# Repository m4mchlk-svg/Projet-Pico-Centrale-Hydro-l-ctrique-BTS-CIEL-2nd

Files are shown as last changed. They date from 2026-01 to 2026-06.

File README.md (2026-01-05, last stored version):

# Projet-Pico-Centrale-Hydro-l-ctrique-BTS-CIEL-2nd

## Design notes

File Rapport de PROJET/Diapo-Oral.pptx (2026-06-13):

## Présentation de Projet

Association Viseta

Descamps Anaël

## Sommaire

1. Partie personnelle
2. Collaboration
3. Diagrammes
4. Mesure et calcul de la consommation
5. Site et codes
6. Schéma et routage
7. Assemblage
8. Problèmes rencontrés
9. Conclusions

## 1) Partie personnelle

- Bilan de consommation : tableau comparatif consommation théorique vs mesurée (modes actif, repos, veille profonde)
- Mise en place du module MPPT et du panneau photovoltaïque et validation de l’autonomie
- Saisie de schéma et routage de la partie concernée du projet
- Programme de test
- Réalisation de l’IHM via une page Web fournie par le contrôleur principal (état du système ECVD et choix de la consigne du niveau d’eau)
- Intégration des différentes fonctions dans le programme final

## 2) Collaboration

Utilisation d’un GitHub pour le partage et l’avancement du projet

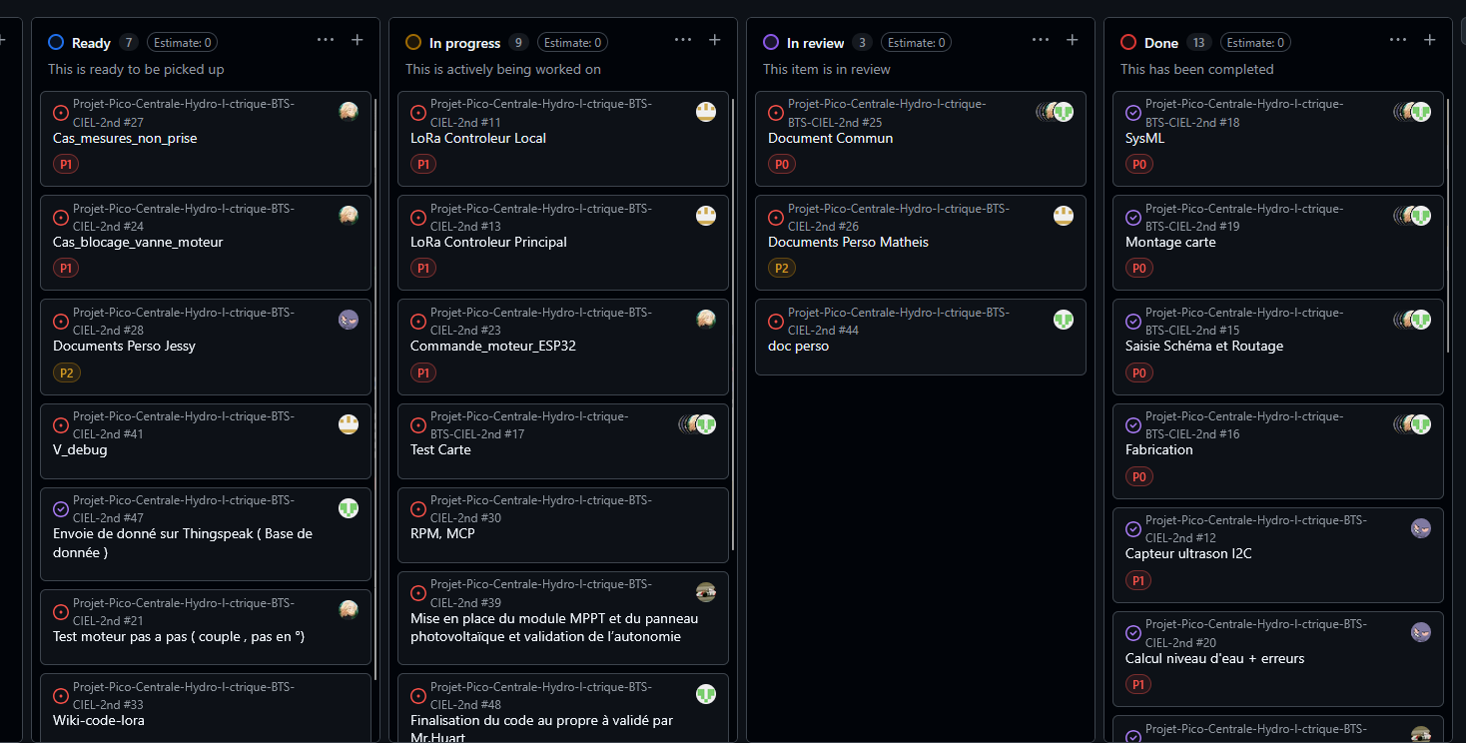
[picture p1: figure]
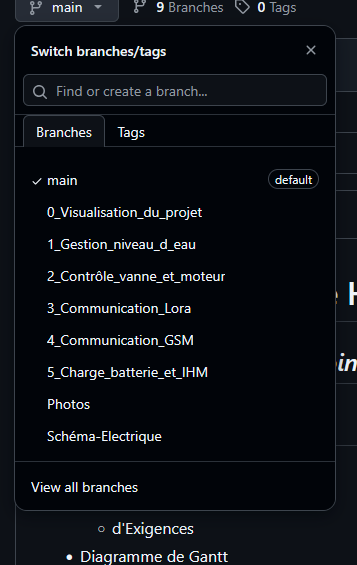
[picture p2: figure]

## 3) Diagrammes

Diagramme des cas d’utilisations

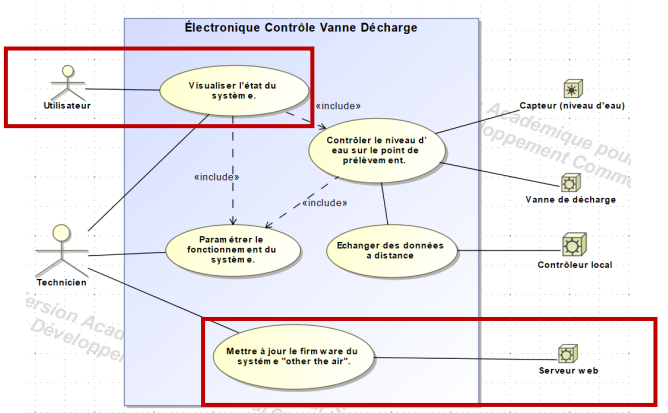
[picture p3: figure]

## 3) Diagrammes

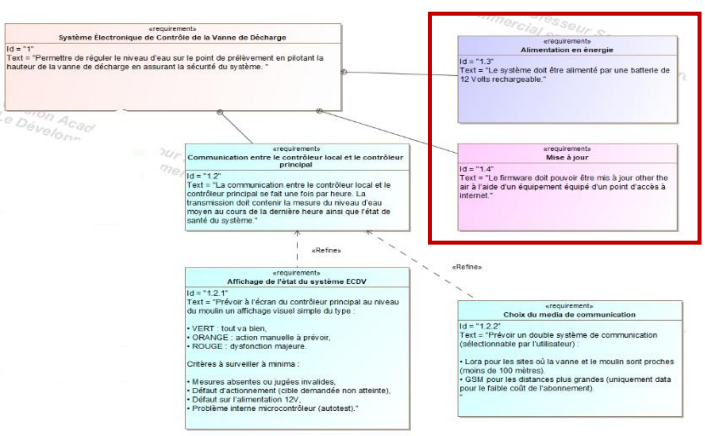
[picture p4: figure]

Diagramme des exigences

## 4) Mesure et calcul de la consommation

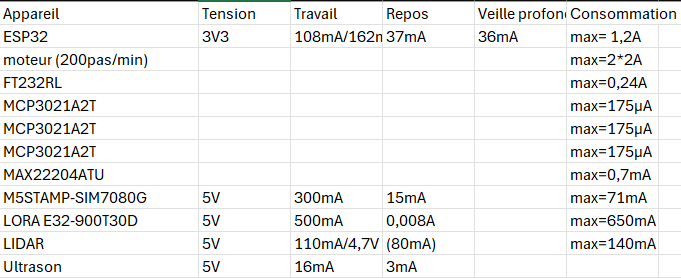
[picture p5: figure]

- Mesure de la consommation de chaque composant principal
- Consommation maximale, au repos et valeurs fabricant (datasheet)
- Composant le plus énergivore : moteur pas-à-pas (ancien moteur)
- Évolution du courant du moteur pas-à-pas en fonction de la vitesse
- Consommation se stabilise à partir d'un certain seuil
- Validation de la batterie 12V retenue pour l'autonomie du système

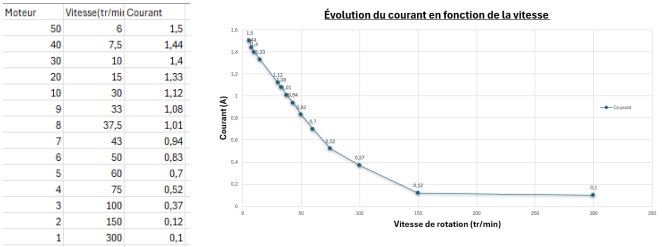
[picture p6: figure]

## 5) Site et codes

- Interface web embarquée (IHM)
- Page HTML hébergée directement sur l’ESP32
- L’ESP32 crée son propre réseau Wi-Fi, accessible directement depuis un téléphone
- Affichage en temps réel : hauteur d’eau, tension batterie, courant solaire
- Envoi des données vers ThingSpeak toutes les 15 secondes
- Accessible sans box ni internet : idéal pour un site isolé comme un moulin

## 5) Site et codes

- Algorigramme du site

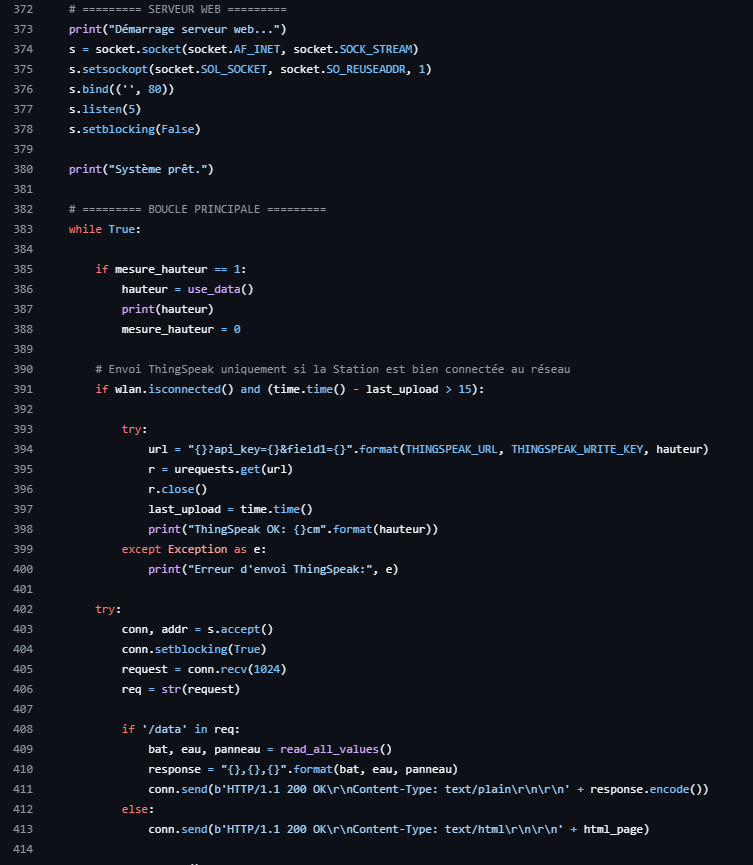
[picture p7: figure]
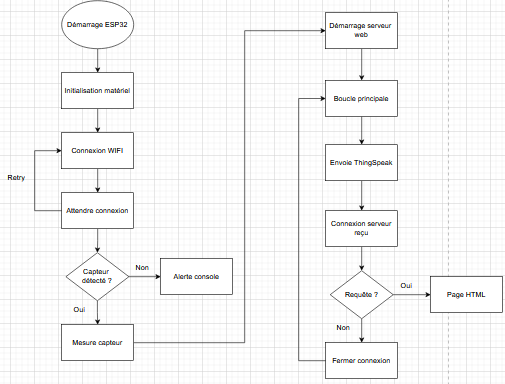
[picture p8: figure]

## 6) Schéma et routage

- Saisie du schéma (Proteus 8)
- Protection contre l’inversion de polarité : MOSFET
- MCP3021 convertisseur analogique numérique
- Régulateur de tension a découpage (U3) : pour convertir la tension 12V en 5V
- AZ1117 convertir la tension de 5V à 3V3

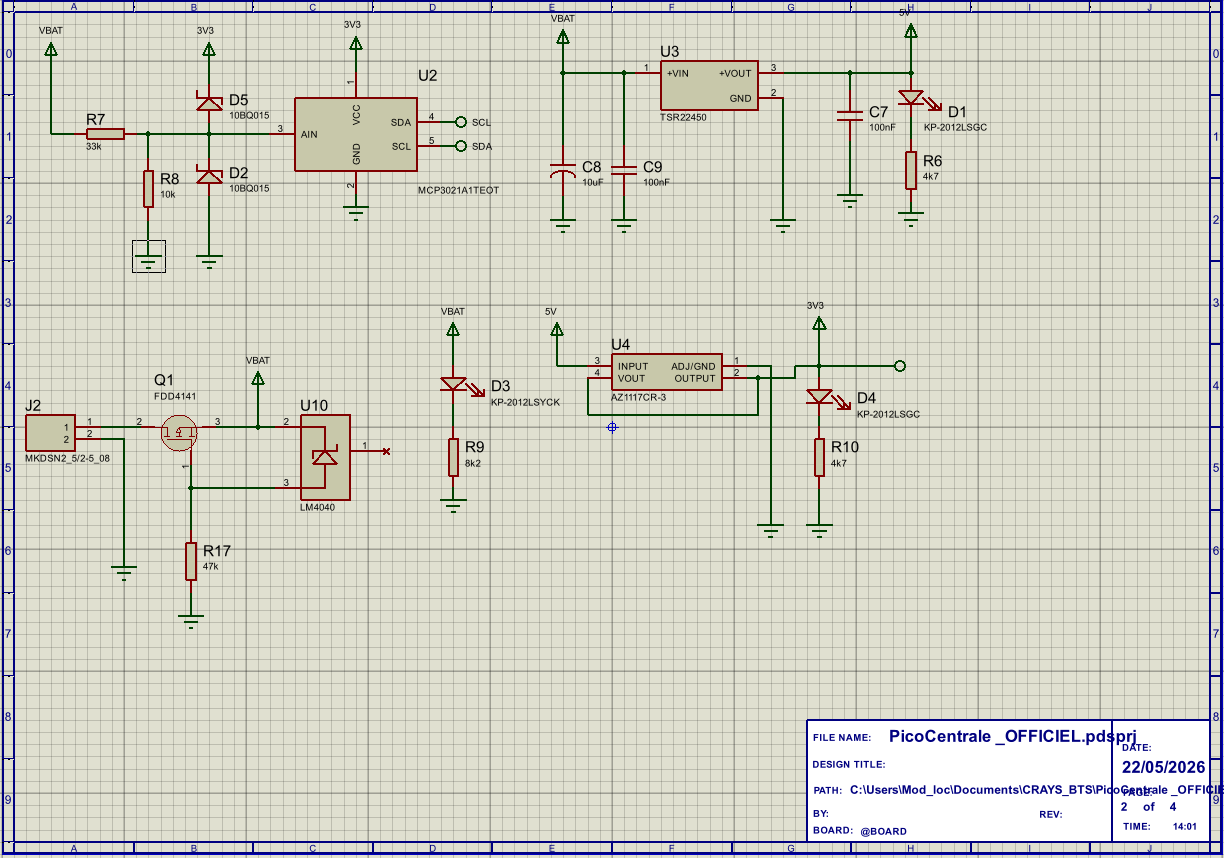
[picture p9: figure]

## 6) Schéma et routage

- Routage PCB
- Séparation des plans de masse numérique (GND) et puissance (VBAT)
- Condensateurs de découplage positionnés au plus près des circuits intégrés
- Pistes de puissance élargies pour la tenue en courant

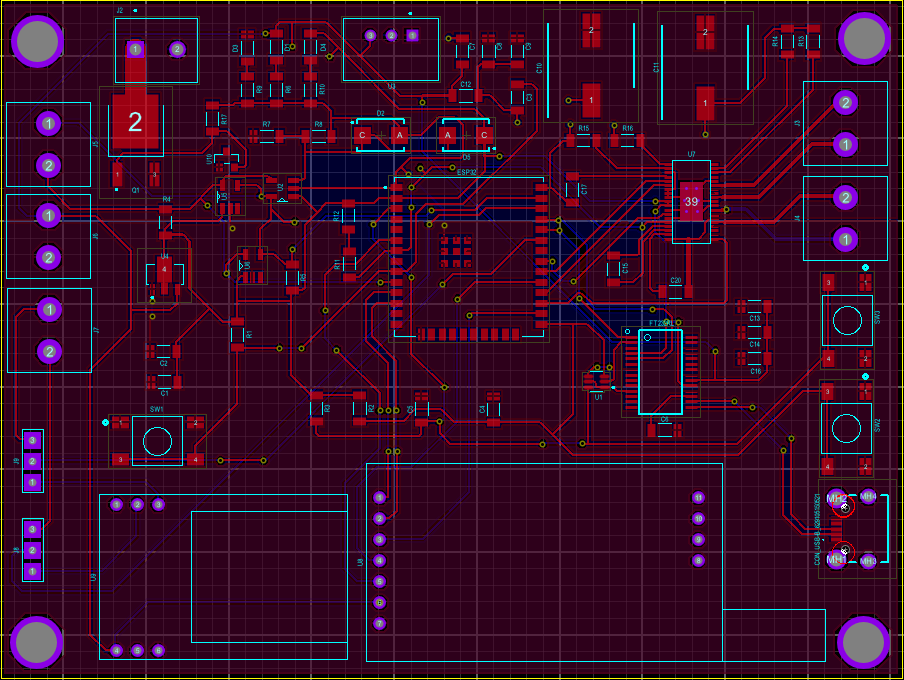
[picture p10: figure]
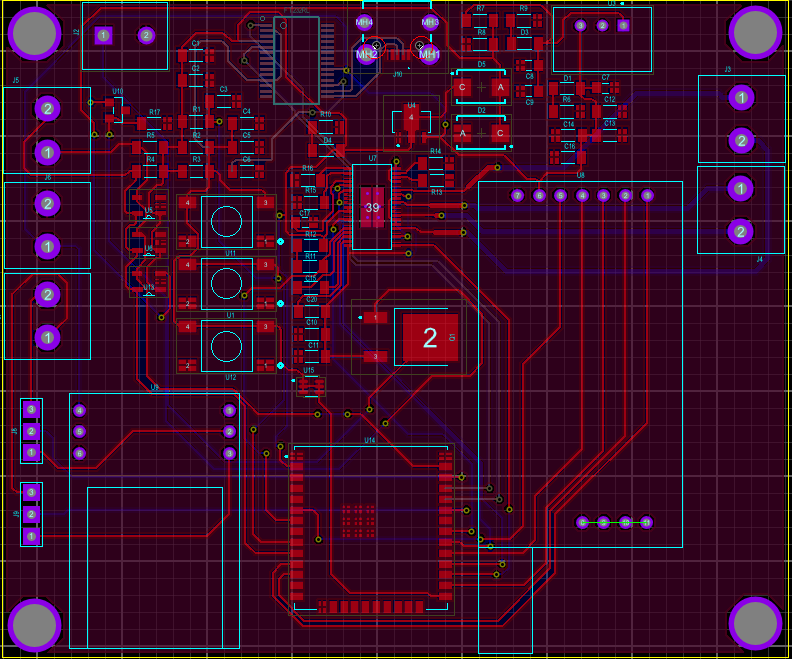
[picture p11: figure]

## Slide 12

6) Schéma et routage

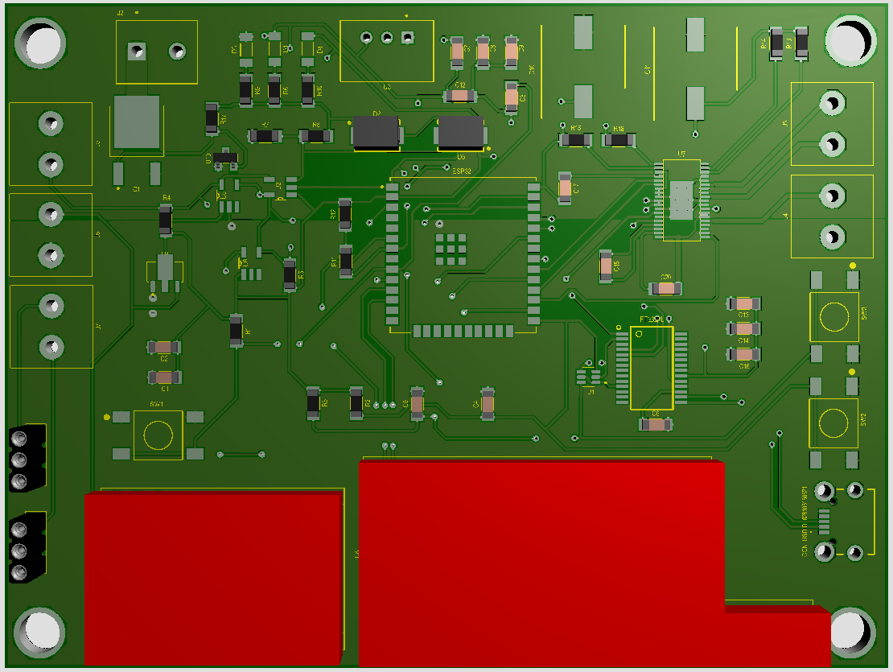
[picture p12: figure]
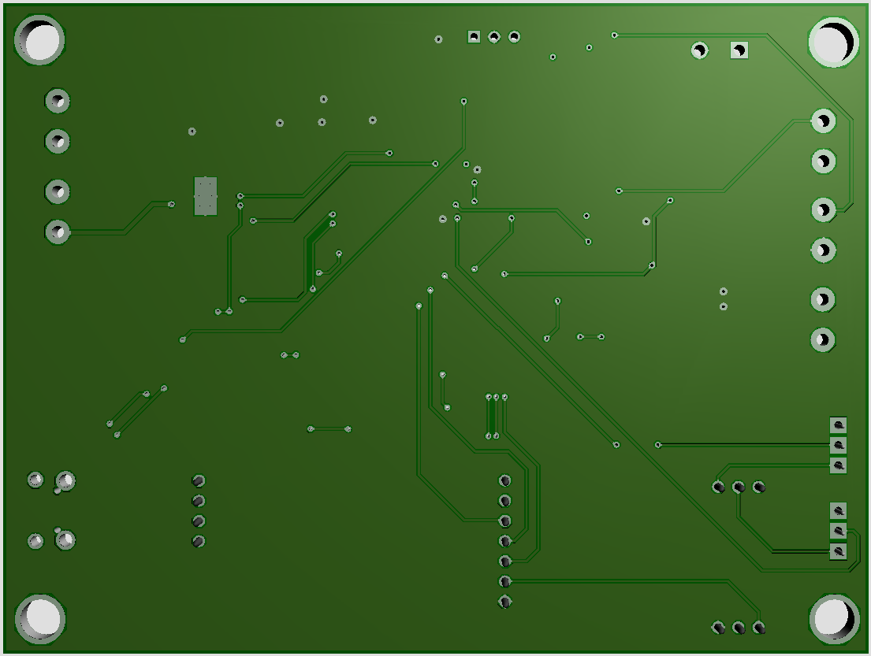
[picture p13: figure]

## 6) Assemblage de la carte

- Réalisé dans les locaux de la Licence CPSE
- Sérigraphie de la pâte à braser
- Pochoir métallique découpé précisément aux emplacements des pastilles PCB
- Étalement à la raclette en un seul passage (port de gants obligatoire)

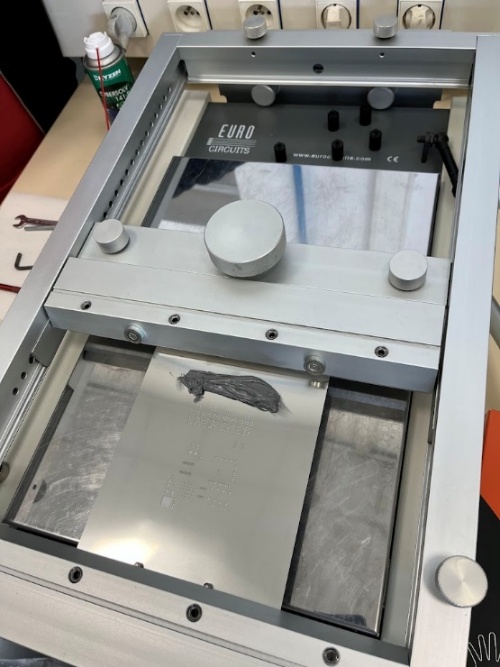
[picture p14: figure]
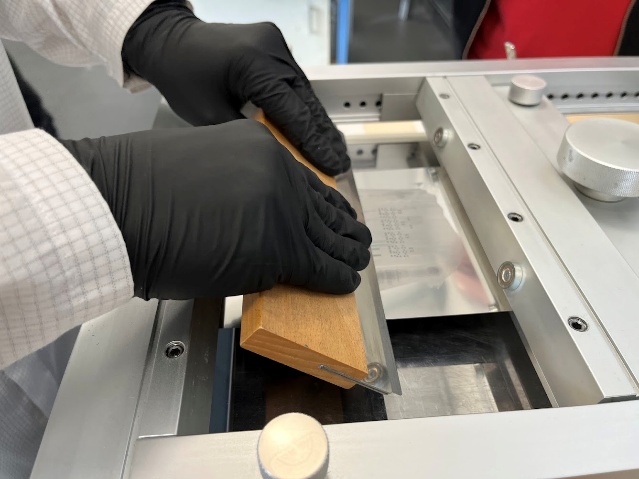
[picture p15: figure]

## 6) Assemblage de la carte

Pose des composants : placeuse à aspiration manuelle et placeuse automatique

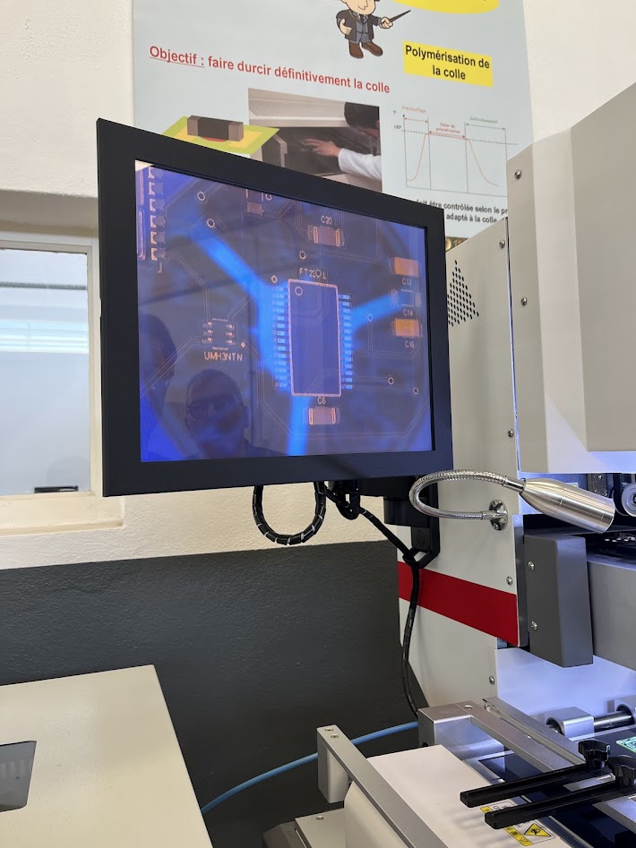
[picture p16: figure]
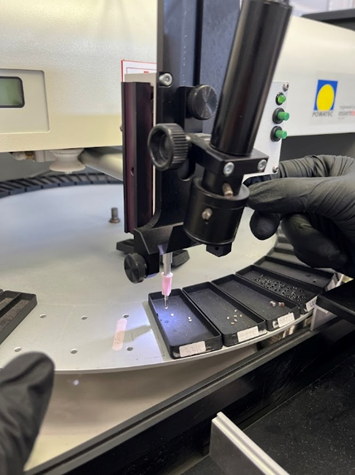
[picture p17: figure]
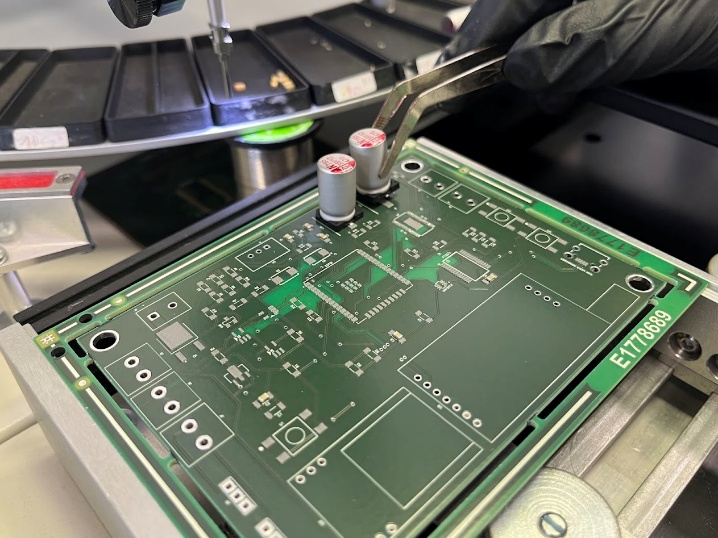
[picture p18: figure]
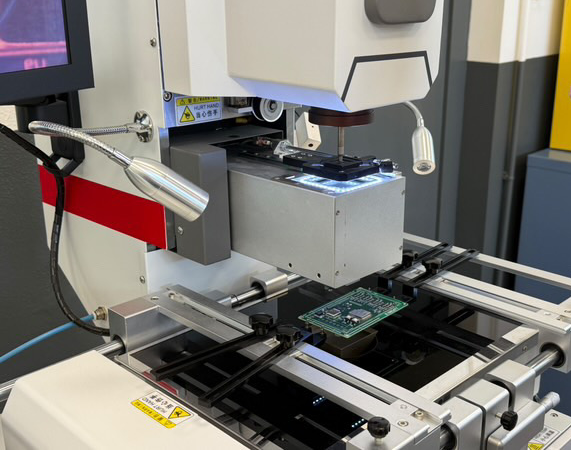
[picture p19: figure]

## 6) Assemblage de la carte

- Refusion au four avec un profil thermique une montée progressive(choc thermique), pic ~250°C puis refroidissement dégressif
- Inspection visuelle à la loupe : détection des ponts de soudure et soudures froides
- Tests fonctionnels bloc par bloc (Lidar, moteur, batterie, serveur web)

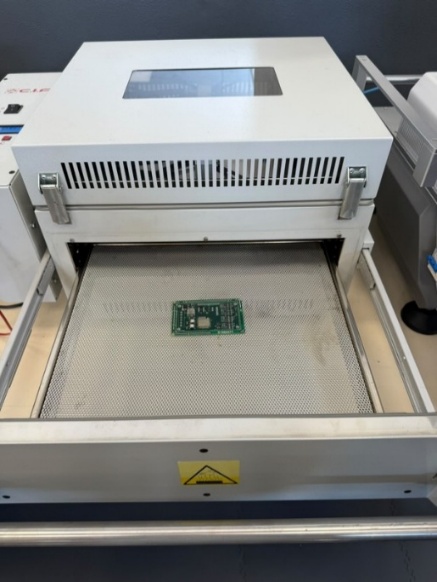
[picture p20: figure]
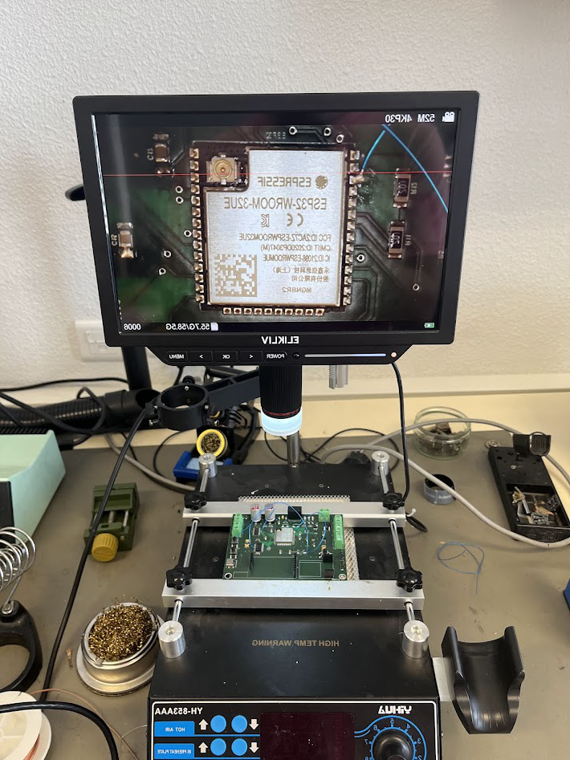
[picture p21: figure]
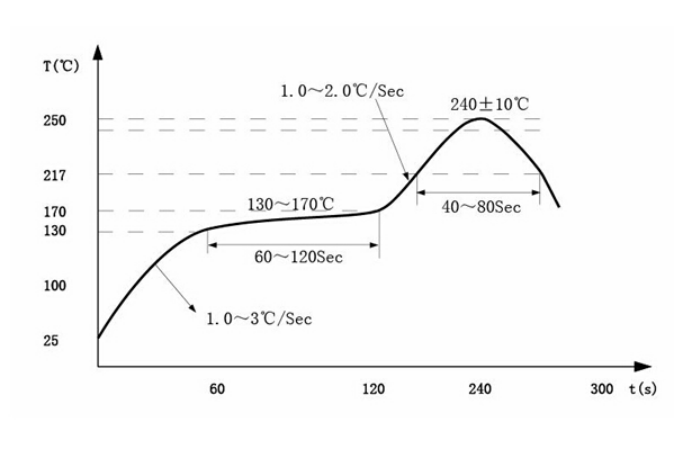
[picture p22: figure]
Type7 High Ag No Clean Solder Paste SAC305 Manufacturers and Suppliers China - Pricelist - BBIEN Technology

## 7) Problèmes rencontrés

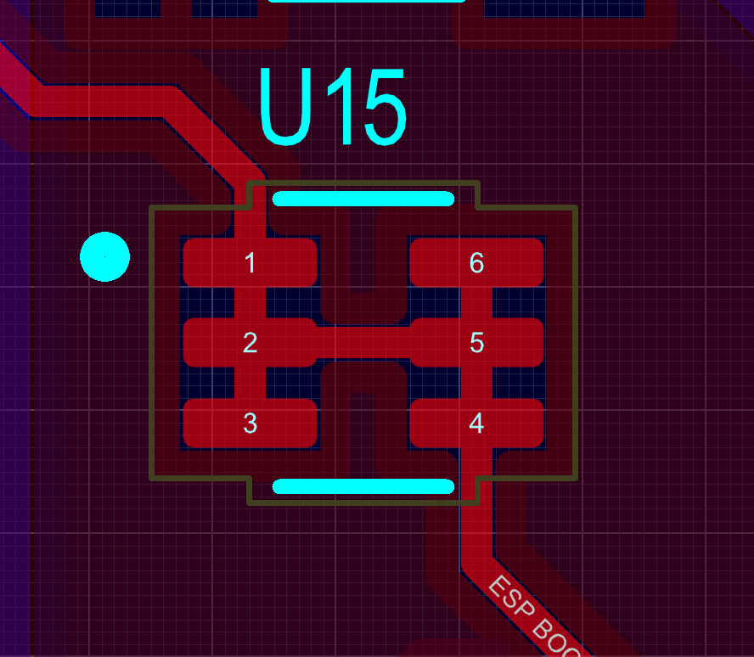
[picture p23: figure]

- Inversion des sorties moteur OUT1A / OUT1B au lieu de OUT1A/OUT2A
- Underscores oubliés dans ESP_RESET et ESP_BOOT
- Broche 18 du FT232RL non connectée au 3,3V
- Empreinte incorrecte sur l’UMH3NTN
- Hétérogénéité des empreintes de résistances

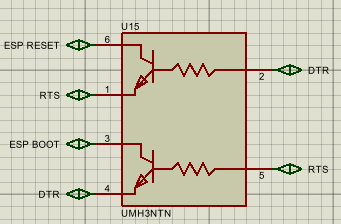
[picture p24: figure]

## 8) Conclusions

- Bilan
Bilan de consommation et dimensionnement de l’alimentation
Vérification et saisie du schéma d’alimentation sur Proteus
Routage PCB et assemblage CMS en conditions industrielles
Développement Micro-Python et une interface web embarquées sur ESP32
- Résultats
Système fonctionnel avec une page web accessible depuis un téléphone via Wi-Fi de l’ESP32,
Approche d’un système électronique autonome : énergie, hardware et software simultanément

## Merci

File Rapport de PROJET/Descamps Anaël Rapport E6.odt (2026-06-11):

BTS CIEL 921

2025-2026

Anaël DESCAMPS

Rapport de Projet


1. Introduction

Dans le cadre de ma formation en BTS CIEL option ER, il nous a été demandé de rédiger un rapport de projet individuel pour présenter le travail qu’on a réalisé tout au long de l’année.

Ce document fait suite au rapport commun intitulé “Rapport commun Pico-centrale hydroélectrique” et se concentre uniquement sur ma contribution personnelle dans ce projet. Pour rappel, l’association Viseta, basée dans les Hautes-Pyrénées, nous a confié la conception de l’électronique de contrôle de la vanne de décharge, qu’on appelle l’ECVD, pour équiper sa pico-centrale hydroélectrique. Une turbine est installée dans un ancien moulin abandonné, et notre système doit réguler automatiquement le niveau d’eau en amont de cette turbine. Pour cela, un capteur Lidar mesure la hauteur d’eau en continu, et en fonction de cette mesure, un moteur pas-à-pas ouvre ou ferme la vanne de décharge. Tout le système fonctionne de manière autonome grâce à une batterie 12V rechargée par un panneau solaire via un régulateur MPPT, ce qui évite d’avoir besoin d’une connexion au réseau électrique. C’est une solution adaptée pour des sites isolés comme des moulins en pleine campagne.

## 1.1. Remerciement

Avant de commencer, je voudrais remercier les personnes qui nous ont aidés et encadrés tout au long de ce projet. Sans leur suivi et leurs conseils, on n’aurait pas pu avancer aussi efficacement :

Toute l’équipe enseignante technique du lycée Antoine Bourdelle, pour les conseils qu’ils nous ont donnés et pour leur suivi régulier du projet, ce qui nous a vraiment permis d’avancer dans la bonne direction :

- M. ALARY

- M. HUART

- M. HAAS

## 1.2. Partie Personnelle

Dans le cadre du projet PICO centrale, j'ai travaillé principalement sur deux aspects : la supervision de la batterie et la conception de l'interface homme-machine (IHM) sous forme de page web embarquée. Ces deux parties sont étroitement liées, dans la mesure où l'IHM affiche en temps réel l'état de la batterie, des panneaux solaires connectés via le module MPPT, ainsi que les données transmises par le capteur de niveau d'eau. L'ensemble permet à l'opérateur de surveiller le système aisément depuis son téléphone.

### 1.2.1. Analyse des besoins énergétiques

J'ai commencé le projet par l'analyse des besoins énergétiques du système, une sous-estimation de la consommation risquerait de compromettre l'autonomie de la batterie la nuit ou par temps couvert. J'ai donc élaboré un tableau Excel recensant, d'une part, la consommation théorique maximale de chaque module, et d'autre part, les valeurs mesurées expérimentalement, en distinguant trois états de fonctionnement : mode actif, repos et veille profonde. Cette comparaison a permis d'évaluer l'écart entre les spécifications fabricant et la consommation réelle, d'identifier les éléments les plus énergivores le moteur pas-à-pas en premier lieu et de confirmer la conformité de la batterie retenue. J'ai également tracé la courbe d'évolution du courant du moteur pas-à-pas en fonction de sa vitesse, afin d'analyser l'impact de la vitesse de déplacement de la vanne sur la consommation et d'ajuster les paramètres du driver en conséquence.

### 1.2.2. Vérification et saisie de la partie alimentation

J'ai ensuite pris en charge la vérification et la saisie de la partie alimentation du projet. Bien que le schéma de base ait été fourni par l'enseignant, j'ai procédé à une vérification et un recalcul des valeurs des composants afin de m'assurer de leur cohérence avec les exigences du système. J'ai notamment recalculé les valeurs des résistances du diviseur de tension utilisé pour la mesure de la batterie via l'ADC de l'ESP32, ainsi que celles des condensateurs de filtrage. J'ai ensuite réalisé la saisie du schéma et le routage de ma section sur Proteus, en veillant à bien séparer les plans de masse numérique et de puissance, afin d'éviter que les perturbations générées par les étages de puissance ne viennent affecter les signaux analogiques, notamment la mesure de tension de la batterie.

### 1.2.3. Intégration et validation du module MPPT

J'ai également assuré l'intégration et la validation du module MPPT couplé au panneau photovoltaïque, qui constitue la source d'énergie principale du système. J'ai vérifié les tensions en sortie du régulateur dans différentes conditions de fonctionnement, mesuré le courant de charge réel, et mis en œuvre dans le code la lecture de la tension batterie via l'ADC de l'ESP32. Ces éléments ont permis de valider l'autonomie énergétique du système sur plusieurs cycles de charge et de décharge.

### 1.2.4. Interface homme-machine (IHM)

Enfin, j'ai participé à la conception et à l'intégration de l'interface utilisateur. Cette page web s'exécute directement sur l'ESP32, sans recours à un serveur externe. Elle est accessible via un réseau Wi-Fi généré par l'ESP32 lui-même, auquel il est possible de se connecter directement depuis un téléphone, sans nécessiter de box ou d'accès Internet. La page affiche la hauteur d'eau, l'état de la batterie, le courant solaire et la position de la vanne, et offre à l'opérateur la possibilité de modifier la consigne de niveau d'eau à distance. L'ensemble a été intégré dans le programme final en Micro Python. J'ai par ailleurs développé un programme de test modulaire permettant de valider chaque sous-ensemble indépendamment avant l'assemblage final, ce qui a facilité l'identification et l'isolation des dysfonctionnements.

### 1.2.5. Bilan

Ce projet m'a permis d'intervenir sur des domaines variés : bilan de consommation, vérification de schémas, routage PCB, développement en Micro Python et conception d'une interface web embarquée. La principale valeur ajoutée de cette expérience réside dans la conduite d'un système électronique complet et autonome de bout en bout, en prenant en compte simultanément les contraintes énergétiques, logicielles et matérielles une approche globale rarement aussi concrète dans le cadre des enseignements habituels.


  3. Diagrammes
2. Mesure et calcul de la tension


Pour commencer, j’ai mesuré la consommation de chaque composant qui risquait de tirer beaucoup de courant, pour vérifier si la batterie initialement prévue était suffisante ou s’il fallait la changer. C’est une étape importante parce que si on se trompe à ce stade, tout le dimensionnement de l’alimentation est faux. J’ai donc fait un tableau Excel, visible ci-dessous, avec pour chaque composant sa consommation maximale, sa consommation au repos, et la valeur théorique indiquée dans sa datasheet. Ça permet de comparer ce que le fabricant annonce avec ce qu’on mesure réellement.


J’ai aussi relevé l’évolution du courant consommé par le moteur pas-à-pas selon sa vitesse. Pour ça, j’ai utilisé le moteur de remplacement que le prof nous a prêté, en attendant le moteur définitif prévu pour le projet, qui est plus puissant, étanche et avec un couple plus élevé. Les mesures montrent que la consommation monte avec la vitesse, ce qui est logique, mais elle finit par se stabiliser à partir d’un certain seuil. Ces infos sont utiles pour régler le driver moteur et éviter de consommer de l’énergie pour rien

3. Création du site et assemblage des codes

Pour cette partie, j’ai créé une page web hébergée directement sur l’ESP32. Elle affiche en temps réel la hauteur d’eau mesurée par le Lidar, la tension de la batterie en volts, et le courant produit ou consommé par le panneau solaire. Pour la partie mesure du niveau d’eau, j’ai récupéré et adapté le code de Jessy dans mon programme, ce qui m’a demandé un peu de travail pour harmoniser les deux codes et faire en sorte que tout fonctionne ensemble sans conflit


La page est pensée pour être consultée depuis un téléphone. L’ESP32 crée son propre réseau Wi-Fi, donc l’opérateur n’a qu’à s’y connecter directement sur le site, sans avoir besoin d’une connexion internet ou d’une box. C’est un vrai plus pour une installation en pleine nature comme un moulin isolé. On a également mis en place une connexion vers ThingSpeak, un service en ligne qui permet d’enregistrer et de visualiser des données sous forme de courbes. Les données sont envoyées toutes les 15 secondes, ce qui correspond au délai minimum proposé par la version gratuite du service. Ça nous permet de suivre l’évolution du niveau d’eau et de détecter d’éventuels problèmes même à distance.


# 4. Algorigrammes

# 5. Saisie de Schéma

## 5.1. Saisie du schéma et routage

À partir du schéma fourni par l'enseignant, nous avons procédé à la saisie sur Proteus 8 avant d'effectuer le routage. Théo et moi avons chacun réalisé notre propre version, et c'est celle de Théo qui a été retenue, car il l'a finalisée en premier. Cette étape s'est révélée particulièrement répétitif : lors des revues de conception, le professeur a relevé plusieurs erreurs qui ont nécessité des corrections répétées. Bien que contraignant, ce processus nous a permis d'assimiler les règles fondamentales du routage : la séparation rigoureuse des plans de masse, le dimensionnement adapté des pistes de puissance, le placement des condensateurs de découplage au plus près des circuits intégrés, etc.

La figure ci-dessous présente le schéma de la partie alimentation que j'ai réalisée, dont je détaillerai les différents blocs dans la suite.

### 5.1.1. Protection contre l'inversion de polarité

Le composant le plus critique de ce schéma est le MOSFET canal P Q1, référencé FDD4141, placé directement en entrée entre la batterie (VBAT) et le reste du circuit. Son rôle est d'assurer une protection totale contre un branchement incorrect de la batterie.

Un MOSFET canal P conduit lorsque sa tension grille-source (Vgs) est négative, lorsque la grille est à un potentiel inférieur à celui de la source. En fonctionnement normal, la résistance R17 (47 kΩ) tire la grille à un potentiel bas, ce qui rend Vgs suffisamment négatif pour ouvrir le canal et laisser circuler librement le courant depuis la batterie vers le reste du circuit. En revanche, si la batterie est branchée à l'envers, Vgs devient positif, le canal se bloque immédiatement et aucun courant ne peut traverser le circuit tous les composants en aval se trouvent ainsi protégés. Le composant U10 (LM4040), une référence de tension de précision de type Zener shunt, contribue à stabiliser la tension de commande de la grille pour garantir un comportement fiable dans toutes les conditions.


### 5.1.2. Condensateur de filtrage C8 et C9

Immédiatement en aval du MOSFET Q1, deux condensateurs sont placés en parallèle sur la ligne VBAT. C8 est un condensateur électrolytique de 10 µF dont le rôle est de lisser les variations basses fréquences et d'absorber les pics de courant provenant de la batterie ou du câblage. C9 est un condensateur céramique de 100 nF qui prend en charge le filtrage des perturbations haute fréquence, notamment le bruit de commutation. L'association de ces deux valeurs permet de couvrir un large spectre de fréquences parasites et de présenter une alimentation propre aux étages suivants.

### 5.1.3. Module MPPT

Le TSR22450 est un régulateur de tension à découpage (Buck Converter) qui convertit la tension VBAT (12V) en une tension stable de 5V pour alimenter les modules consommateurs. Contrairement à un régulateur linéaire classique, il fonctionne par commutation à haute fréquence, ce qui lui permet d'atteindre un rendement d'environ 96% en limitant les pertes thermiques un avantage important dans un système alimenté sur batterie. En contrepartie, cette commutation génère des perturbations haute fréquence sur ses lignes d'alimentation ; c'est pourquoi deux condensateurs de découplage C8 et C9 sont placés en entrée du module pour les filtrer et éviter qu'elles ne se propagent au reste du circuit. Un

condensateur C7 est également présent en sortie pour stabiliser la tension délivrée.

### 5.1.4. Convertisseur analogique-numérique MCP3021


Le MCP3021 est également intégré à ce schéma. Il permet d'acquérir la tension de la batterie avec une précision supérieure à celle de l'ADC interne de l'ESP32, en communiquant avec ce dernier via le bus I2C. C'est cette mesure qui permet d'afficher l'état de charge de la batterie sur l'interface web.

Formule pour le diviseur de tension :

### 5.1.5 LEDs indicatrices


Enfin, des LEDs sont présentes sur le schéma. Elles servent uniquement d'indicateurs visuels : quand une LED est allumée, ça confirme que la tension correspondante est bien présente sur la carte. C'est pratique lors des tests et de la mise au point pour vérifier d'un coup d'œil que l'alimentation fonctionne correctement.

Courant de la LED

Puissance dissipée dans R10 :

## 5.2. Schéma Alimentation avant modification :


## 5.3. Routage final effectuer par Théo :


## 5.5. Mon routage :

# 6. Assemblage de la carte

## 6.1. Sérigraphie de la pâte à braser

Grâce aux installations de la licence CPSE, l'assemblage de la carte a pu être réalisé dans des conditions très proches d'un environnement industriel professionnel. La première étape a consisté à déposer la pâte à braser sur les pastilles du PCB à l'aide d'un pochoir métallique. Ce pochoir est une feuille d'acier découpée avec précision aux emplacements exacts des pastilles, ce qui garantit que la pâte se dépose uniquement aux endroits nécessaires, sans débordement sur les zones isolantes. La pâte est étalée à la raclette en un seul passage régulier pour obtenir des dépôts homogènes et d'épaisseur uniforme. Le port de gants est obligatoire durant cette manipulation car la pâte à braser contient des composés chimiques irritants au contact de la peau. Une fois le pochoir soigneusement retiré, on peut observer sur chaque pastille un petit dépôt de pâte grisâtre bien délimité, prêt à recevoir les composants.

## 6.2. Pose des composants

La pose des composants s'est déroulée en deux phases selon leur taille et leur précision de placement requise. Les composants passifs de petite taille, résistances et condensateurs CMS, ont été placés manuellement à l'aide d'une placeuse à aspiration. Cet outil fonctionne comme une pince pneumatique : une légère dépression maintient le composant en suspension au bout de l'embout, ce qui permet de le positionner délicatement sur les dépôts de pâte sans ne le déplacer ni le contaminer. Pour les composants plus grands et surtout plus exigeants en termes de précision de placement, comme l'ESP32 dont le pas des broches est très fin, la placeuse automatique Pick and Place a été utilisée. Les composants sont d'abord déposés manuellement à proximité, puis la machine les récupère, les centre optiquement et les pose avec une précision micrométrique qu'aucune intervention humaine directe ne pourrait atteindre de manière reproductible.

## 6.3. Refusion au four

Une fois l'ensemble des composants en place sur leurs dépôts de pâte, la carte a été introduite dans le four de refusion. Ce four applique un profil thermique précisément contrôlé, composé de plusieurs phases distinctes. La première phase est une montée progressive en température qui active le flux contenu dans la pâte à braser : ce flux a pour rôle de nettoyer chimiquement les surfaces métalliques et de les préparer à former des liaisons soudées de qualité. Vient ensuite le pic de température, typiquement autour de 250 °C pour un alliage sans plomb, qui fait fondre l'alliage de la pâte et crée les joints de soudure entre les broches des composants et les pastilles du PCB. Enfin, un refroidissement contrôlé permet à l'alliage de se solidifier progressivement en formant des soudures brillantes et mécaniquement solides, en évitant les contraintes thermiques qui pourraient fragiliser les joints ou endommager certains composants sensibles.

## 6.4. Inspection et contrôle qualité

À la sortie du four, chaque soudure a été inspectée visuellement à la loupe afin de détecter d'éventuels défauts. Les deux défauts les plus courants en refusion sont les ponts de soudure des courts-circuits involontaires entre deux broches adjacentes provoqués par un excès de pâte et les soudures froides, reconnaissables à leur aspect mat et granuleux, qui traduisent une mauvaise mouillabilité et une liaison électrique ou mécanique insuffisante. Des tests de continuité au multimètre ont ensuite été réalisés sur les connexions les plus critiques du circuit pour confirmer l'absence de coupures ou de court-circuit non détectés visuellement.

## 6.5. Mise sous tension et tests fonctionnels

Avant de procéder aux tests logiciels, la carte a d'abord été mise sous tension avec précaution pour vérifier que la consommation de courant se situait dans les valeurs attendues et qu'aucun composant ne chauffait anormalement, ce qui aurait pu signaler un problème de soudure ou un défaut de conception. Une fois ce premier contrôle validé, le firmware Micro Python a été flashé sur l'ESP32 et les tests fonctionnels ont été conduits de manière séquentielle, bloc par bloc. Le capteur Lidar, le driver du moteur pas-à-pas, la lecture de la tension batterie via le MCP3021 et le serveur web embarqué ont chacun été testés et validés indépendamment avant de passer au suivant. Cette méthode de validation progressive permet de localiser précisément l'origine d'un éventuel dysfonctionnement et d'éviter de chercher une panne dans l'ensemble du système en même temps.

# 7. Problèmes rencontrés

Sur la carte V1, nous avons rencontré plusieurs problèmes qui nous ont bien bloqués avant de réussir à tous les identifier. Certains étaient des erreurs de schéma, d'autres venaient des empreintes des composants.

### 7.1. Inversion des sorties moteur

La première erreur détectée concernait le câblage des sorties du driver moteur. Les sorties OUT1A et OUT1B avaient été inversées dans le schéma électrique, ce qui faisait tourner le moteur dans le sens opposé à celui attendu. Bien que cette erreur n'ait pas empêché la carte de fonctionner électriquement, elle rendait le comportement du système incohérent et aurait compromis le bon fonctionnement mécanique de l'ensemble. La correction a consisté à intervertir les deux connexions dans le schéma lors du passage en V2.

### 7.2. Oubli des underscores dans les labels ESP_RESET et ESP_BOOT

Les underscores avaient été oublié dans les noms des labels ESP_RESET et ESP_BOOT, ce qui empêchait le logiciel de reconnaître les liaisons correspondantes. Les broches se retrouvaient électriquement coupées, rendant la programmation de l'ESP32 impossible. Le diagnostic a pris du temps précisément parce que l'origine du problème était une simple faute de frappe dans un nom de net, ce qui a renforcé l'importance d'une relecture rigoureuse des labels avant toute opération de routage.

### 7.3. Broche non connectée sur le FT232RL

Le FT232RL assure la communication USB entre l'ordinateur et l'ESP32. Sur la V1, sa broche 18 n'était pas reliée au 3,3 V, ce qui rendait la connexion USB instable et la programmation peu fiable. Une fois le problème localisé à partir de la datasheet, la correction était directe : il suffisait d'ajouter la connexion manquante dans le schéma de la V2.

### 7.4. Court-circuit provoqué par une empreinte incorrecte sur l'UMH3NTN

L'UMH3NTN avait été créé manuellement dans la bibliothèque de composants du projet. Une erreur de correspondance entre les broches du schéma et celles de l'empreinte physique a provoqué un court-circuit à la mise sous tension. Ce type d'erreur est difficile à anticiper car il n'apparaît pas dans le schéma et ne se manifeste qu'à l'assemblage. Cela a conduit à adopter une vérification systématique de chaque composant créé sur mesure, en le comparant point par point avec la datasheet du fabricant.


### 7.5. Hétérogénéité des empreintes de résistances

Enfin, les résistances présentes sur la carte ne partageaient pas toutes la même empreinte, c'est-à-dire que leurs dimensions physiques variaient d'un composant à l'autre sur le PCB. Cette incohérence a compliqué l'étape de soudage, notamment lors de la sérigraphie de la pâte à braser et du placement des composants, car les gabarits et les réglages ne correspondaient pas uniformément à l'ensemble des résistances. Sur la V2, une harmonisation des empreintes a été réalisée pour garantir une cohérence dimensionnelle sur toute la carte et faciliter l'assemblage.

# 8. Conclusion

Ce projet avec l'association Viseta m'a demandé de travailler sur plusieurs aspects comme le bilan de consommation, le schéma d'alimentation, le routage sur Proteus, l'assemblage de la carte et le développement en Micro-Python.

Le bilan de consommation a été une étape importante pour dimensionner correctement l'alimentation et s'assurer que chaque composant disposait de la tension et du courant nécessaires à son bon fonctionnement. Cela m'a permis de mieux comprendre les contraintes liées à l'autonomie et au choix des régulateurs.

La partie logicielle a aussi nécessité un peu d'adaptation, notamment pour intégrer le code du Lidar de Jessy sans casser le reste. Il a fallu comprendre la structure existante, identifier les conflits potentiels et réorganiser certaines parties du code pour que les différents modules cohabitent correctement. Finalement le système fonctionne la page web est accessible depuis un téléphone directement sur le réseau Wi-Fi de l'ESP32, sans avoir besoin d'internet. C'est un résultat concret et satisfaisant, car il rend le système utilisable facilement sur le terrain sans infrastructure réseau particulière.

L'assemblage dans les locaux de la licence CPSE était une bonne expérience. Le pochoir, la placeuse automatique, le four de refusion, c'est du matériel qu'on utilise rarement et qui nous permet de nous projeter sur ce que représente concrètement la fabrication d'une carte électronique. Pour voir la carte passer du stade de fichiers Gerber à un PCB assemblé et fonctionnel donne une vraie dimension industrielle au projet.

Les problèmes rencontrés sur la V1 ont pris du temps à être identifiés, surtout ceux liés aux empreintes incorrectes et aux labels mal assignés dans le schéma. Ces erreurs, souvent invisibles à première vue, peuvent pourtant bloquer complètement le fonctionnement d'un circuit. Mais ça m'a forcé à être plus rigoureux et plus méthodique, notamment sur la vérification des composants créés manuellement et sur la relecture attentive des schémas avant de passer à l'étape du routage. C'est ce genre d'expérience qui forge les bons réflexes pour les projets à venir.

# 9. Annexes


Etalement de la pâte du le pochoir

Pose de la pâte a braser sur le pochoir


Image du PCB et de la pose de composants plus important

Pose des composants dans la station de placement


Placeuse automatique

Image du placement du FT232RL avec la placeuse automatique


Image du four

Vérification des pins de certains composants

Vue 3D de la carte (devant)


Vue 3D de la carte (derrière)

22/24 DESCAMPS Anaël – Lycée Polyvalent Antoine Bourdelle BTS CIEL option ER

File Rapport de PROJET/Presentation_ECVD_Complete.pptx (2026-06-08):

## Présentation de Projet

Lycée Antoine Bourdelle | LinkedIn

Association Visseta

Descamps Anaël

## Sommaire

1. Diagrammes
2. Mesure et calcul de la tension
3. Site et codes
4. Schéma et routage
5. Assemblage
6. Problèmes rencontres
7. Conclusion

## 1) Diagrammes

Cas d’utilisation et cas d’exigences


## 2) Mesure et calcul de la tension

- Mesure de chaque gros composant utilisé sur la carte
- Consommation max et min plus datasheet
- Mesure de courant du premier moteur


## 3) Site et codes


- Interface web embarquee (IHM)
- Page HTML hebergee directement sur l’ESP32
- L’ESP32 cree son propre reseau Wi-Fi connexion directement depuis un téléphone
- Affichage en temps reel : hauteur d’eau, tension batterie, courant solaire, position vanne
- Envoi des donnees vers ThingSpeak toutes les 15 secondes


## 3) Site et codes

- Assemblage des codes (Micro Python)
- Intégration du code Lidar de Jessy dans le programme principal
- Programme de test modulaire : validation de chaque sous-ensemble indépendamment
- Algorigramme


## 4) Schema et routage


- Saisie du schema (Proteus 8)
- Protection contre l’inversion de polarite : MOSFET canal P (FDD4141)
- Condensateurs de filtrage C8 (10 uF) et C9 (100 nF) : filtrage BF et HF
- Module MPPT (TSR22450) : recharge batterie au point de puissance max du panneau


## 4) Schema et routage


- Convertisseur ADC MCP3021 (I2C) : mesure tension batterie, VAIN = VBAT x 10k / (33k+10k)
- LEDS et indicateurs visuels


## 4) Schema et routage

- Routage PCB
- Plusieurs plans de masse (VBAT, GND)
- Routage final


## 4) Schéma et routage


Mon routage

Routage final (Théo)

## 5) Assemblage de la carte

- Realise dans les locaux de la Licence CPSE (materiel industriel)
- Serigraphie de la pate a braser : pochoir acier, depot homogene a la raclette
- Pose des composants : placeuse a aspiration (CMS) + placeuse automatique Pick & Place (ESP32)
- Refusion au four : profil thermique controle, pic ~250 degres C, refroidissement progressif
- Inspection : loupe (ponts de soudure, soudures froides) + multimetre (tests de continuite)
- Tests fonctionnels bloc par bloc : Lidar, driver moteur, MCP3021, serveur web
- De Gerber a carte fonctionnelle : une experience industrielle concrete

## 6) Problemes rencontres

- Inversion des sorties moteur OUT1A / OUT1B → moteur tournait dans le mauvais sens → correction dans le schema V2
- Underscores oublies dans ESP_RESET et ESP_BOOT → liaisons coupees, programmation impossible → correction des labels
- Broche 18 FT232RL non connectee au 3V3 → connexion USB instable → connexion ajoutee via la datasheet
- Empreinte incorrecte sur l’UMH3NTN → court-circuit a la mise sous tension → verification point par point avec la datasheet
- Heterogeneite des empreintes de resistances → problemes de soudage et serigraphie → harmonisation complete sur la V2

## 7) Conclusion

- Bilan des competences mobilisees
- Bilan de consommation et dimensionnement de l’alimentation
- Verification et saisie du schema d’alimentation sur Proteus
- Routage PCB et assemblage CMS en conditions industrielles
- Developpement MicroPython et interface web embarquee sur ESP32
- Resultat concret
- Systeme fonctionnel : page web accessible depuis un telephone via Wi-Fi de l’ESP32, sans internet
- Approche globale d’un systeme electronique autonome : energie, hardware et software simultanement
- Bons reflexes acquis : rigueur sur empreintes, relecture des labels, validation bloc par bloc

## Merci

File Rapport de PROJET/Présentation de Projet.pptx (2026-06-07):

## Présentation de Projet

Lycée Antoine Bourdelle | LinkedIn

Association Visseta

Descamps Anaël

## Sommaire

1. Diagrammes
2. Mesure et calcul de la tension
3. Site et codes
4. Schéma et routage
5. Assemblage
6. Problèmes rencontres
7. Conclusion

## 1) Diagrammes

Cas d’utilisation et cas d’exigences


## Mesure et calcul de la tension


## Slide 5

## Merci

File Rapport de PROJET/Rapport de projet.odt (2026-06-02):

BTS CIEL 921

2025-2026

Anaël DESCAMPS

Rapport de Projet


1. Introduction

Dans le cadre de ma formation en BTS CIEL option ER, il nous a été demandé de rédiger un rapport de projet individuel pour présenter le travail qu’on a réalisé tout au long de l’année.

Ce document fait suite au rapport commun intitulé “Rapport commun Pico-centrale hydroélectrique” et se concentre uniquement sur ma contribution personnelle dans ce projet. Pour rappel, l’association Viseta, basée dans les Hautes-Pyrénées, nous a confié la conception de l’électronique de contrôle de la vanne de décharge, qu’on appelle l’ECVD, pour équiper sa pico-centrale hydroélectrique. Une turbine est installée dans un ancien moulin abandonné, et notre système doit réguler automatiquement le niveau d’eau en amont de cette turbine. Pour cela, un capteur Lidar mesure la hauteur d’eau en continu, et en fonction de cette mesure, un moteur pas-à-pas ouvre ou ferme la vanne de décharge. Tout le système fonctionne de manière autonome grâce à une batterie 12V rechargée par un panneau solaire via un régulateur MPPT, ce qui évite d’avoir besoin d’une connexion au réseau électrique. C’est une solution adaptée pour des sites isolés comme des moulins en pleine campagne.

## 1.1. Remerciement

Avant de commencer, je voudrais remercier les personnes qui nous ont aidés et encadrés tout au long de ce projet. Sans leur suivi et leurs conseils, on n’aurait pas pu avancer aussi efficacement :

Toute l’équipe enseignante technique du lycée Antoine Bourdelle, pour les conseils qu’ils nous ont donnés et pour leur suivi régulier du projet, ce qui nous a vraiment permis d’avancer dans la bonne direction :

- M. ALARY

- M. HUART

- M. HAAS

## 1.2. Partie Personnel

Dans le cadre du projet PICO centrale, j'ai travaillé principalement sur deux aspects : la supervision de la batterie et la conception de l'interface homme-machine (IHM) sous forme de page web embarquée. Ces deux parties sont étroitement liées, dans la mesure où l'IHM affiche en temps réel l'état de la batterie, des panneaux solaires connectés via le module MPPT, ainsi que les données transmises par le capteur de niveau d'eau. L'ensemble permet à l'opérateur de surveiller le système aisément depuis son téléphone.

### 1.2.1. Analyse des besoins énergétiques

J'ai commencé le projet par l'analyse des besoins énergétiques du système, une sous-estimation de la consommation risquerait de compromettre l'autonomie de la batterie la nuit ou par temps couvert. J'ai donc élaboré un tableau Excel recensant, d'une part, la consommation théorique maximale de chaque module, et d'autre part, les valeurs mesurées expérimentalement, en distinguant trois états de fonctionnement : mode actif, repos et veille profonde. Cette comparaison a permis d'évaluer l'écart entre les spécifications fabricant et la consommation réelle, d'identifier les éléments les plus énergivores le moteur pas-à-pas en premier lieu et de confirmer la conformité de la batterie retenue. J'ai également tracé la courbe d'évolution du courant du moteur pas-à-pas en fonction de sa vitesse, afin d'analyser l'impact de la vitesse de déplacement de la vanne sur la consommation et d'ajuster les paramètres du driver en conséquence.

### 1.2.2. Vérification et saisie de la partie alimentation

J'ai ensuite pris en charge la vérification et la saisie de la partie alimentation du projet. Bien que le schéma de base ait été fourni par l'enseignant, j'ai procédé à une vérification et un recalcul des valeurs des composants afin de m'assurer de leur cohérence avec les exigences du système. J'ai notamment recalculé les valeurs des résistances du diviseur de tension utilisé pour la mesure de la batterie via l'ADC de l'ESP32, ainsi que celles des condensateurs de filtrage. J'ai ensuite réalisé la saisie du schéma et le routage de ma section sur Proteus, en veillant à bien séparer les plans de masse numérique et de puissance, afin d'éviter que les perturbations générées par les étages de puissance ne viennent affecter les signaux analogiques, notamment la mesure de tension de la batterie.

### 1.2.3. Intégration et validation du module MPPT

J'ai également assuré l'intégration et la validation du module MPPT couplé au panneau photovoltaïque, qui constitue la source d'énergie principale du système. J'ai vérifié les tensions en sortie du régulateur dans différentes conditions de fonctionnement, mesuré le courant de charge réel, et mis en œuvre dans le code la lecture de la tension batterie via l'ADC de l'ESP32. Ces éléments ont permis de valider l'autonomie énergétique du système sur plusieurs cycles de charge et de décharge.

### 1.2.4. Interface homme-machine (IHM)

Enfin, j'ai participé à la conception et à l'intégration de l'interface utilisateur. Cette page web s'exécute directement sur l'ESP32, sans recours à un serveur externe. Elle est accessible via un réseau Wi-Fi généré par l'ESP32 lui-même, auquel il est possible de se connecter directement depuis un téléphone, sans nécessiter de box ou d'accès Internet. La page affiche la hauteur d'eau, l'état de la batterie, le courant solaire et la position de la vanne, et offre à l'opérateur la possibilité de modifier la consigne de niveau d'eau à distance. L'ensemble a été intégré dans le programme final en Micro Python. J'ai par ailleurs développé un programme de test modulaire permettant de valider chaque sous-ensemble indépendamment avant l'assemblage final, ce qui a facilité l'identification et l'isolation des dysfonctionnements.

### 1.2.5. Bilan

Ce projet m'a permis d'intervenir sur des domaines variés : bilan de consommation, vérification de schémas, routage PCB, développement en Micro Python et conception d'une interface web embarquée. La principale valeur ajoutée de cette expérience réside dans la conduite d'un système électronique complet et autonome de bout en bout, en prenant en compte simultanément les contraintes énergétiques, logicielles et matérielles une approche globale rarement aussi concrète dans le cadre des enseignements habituels.


  3. Diagrammes
2. Mesure et calcul de la tension


Pour commencer, j’ai mesuré la consommation de chaque composant qui risquait de tirer beaucoup de courant, pour vérifier si la batterie initialement prévue était suffisante ou s’il fallait la changer. C’est une étape importante parce que si on se trompe à ce stade, tout le dimensionnement de l’alimentation est faux. J’ai donc fait un tableau Excel, visible ci-dessous, avec pour chaque composant sa consommation maximale, sa consommation au repos, et la valeur théorique indiquée dans sa datasheet. Ça permet de comparer ce que le fabricant annonce avec ce qu’on mesure réellement.


J’ai aussi relevé l’évolution du courant consommé par le moteur pas-à-pas selon sa vitesse. Pour ça, j’ai utilisé le moteur de remplacement que le prof nous a prêté, en attendant le moteur définitif prévu pour le projet, qui est plus puissant, étanche et avec un couple plus élevé. Les mesures montrent que la consommation monte avec la vitesse, ce qui est logique, mais elle finit par se stabiliser à partir d’un certain seuil. Ces infos sont utiles pour régler le driver moteur et éviter de consommer de l’énergie pour rien

3. Création du site et assemblage des codes

Pour cette partie, j’ai créé une page web hébergée directement sur l’ESP32. Elle affiche en temps réel la hauteur d’eau mesurée par le Lidar, la tension de la batterie en volts, et le courant produit ou consommé par le panneau solaire. Pour la partie mesure du niveau d’eau, j’ai récupéré et adapté le code de Jessy dans mon programme, ce qui m’a demandé un peu de travail pour harmoniser les deux codes et faire en sorte que tout fonctionne ensemble sans conflit


La page est pensée pour être consultée depuis un téléphone. L’ESP32 crée son propre réseau Wi-Fi, donc l’opérateur n’a qu’à s’y connecter directement sur le site, sans avoir besoin d’une connexion internet ou d’une box. C’est un vrai plus pour une installation en pleine nature comme un moulin isolé. On a également mis en place une connexion vers ThingSpeak, un service en ligne qui permet d’enregistrer et de visualiser des données sous forme de courbes. Les données sont envoyées toutes les 15 secondes, ce qui correspond au délai minimum proposé par la version gratuite du service. Ça nous permet de suivre l’évolution du niveau d’eau et de détecter d’éventuels problèmes même à distance.


# 4. Algorigrammes

# 5. Saisie de Schéma

## 5.1. Saisie du schéma et routage

À partir du schéma fourni par l'enseignant, nous avons procédé à la saisie sur Proteus 8 avant d'effectuer le routage. Théo et moi avons chacun réalisé notre propre version, et c'est celle de Théo qui a été retenue, car il l'a finalisée en premier. Cette étape s'est révélée particulièrement répétitif : lors des revues de conception, le professeur a relevé plusieurs erreurs qui ont nécessité des corrections répétées. Bien que contraignant, ce processus nous a permis d'assimiler les règles fondamentales du routage : la séparation rigoureuse des plans de masse, le dimensionnement adapté des pistes de puissance, le placement des condensateurs de découplage au plus près des circuits intégrés, etc.

La figure ci-dessous présente le schéma de la partie alimentation que j'ai réalisée, dont je détaillerai les différents blocs dans la suite.

### 5.1.1. Protection contre l'inversion de polarité

Le composant le plus critique de ce schéma est le MOSFET canal P Q1, référencé FDD4141, placé directement en entrée entre la batterie (VBAT) et le reste du circuit. Son rôle est d'assurer une protection totale contre un branchement incorrect de la batterie.

Un MOSFET canal P conduit lorsque sa tension grille-source (Vgs) est négative, lorsque la grille est à un potentiel inférieur à celui de la source. En fonctionnement normal, la résistance R17 (47 kΩ) tire la grille à un potentiel bas, ce qui rend Vgs suffisamment négatif pour ouvrir le canal et laisser circuler librement le courant depuis la batterie vers le reste du circuit. En revanche, si la batterie est branchée à l'envers, Vgs devient positif, le canal se bloque immédiatement et aucun courant ne peut traverser le circuit tous les composants en aval se trouvent ainsi protégés. Le composant U10 (LM4040), une référence de tension de précision de type Zener shunt, contribue à stabiliser la tension de commande de la grille pour garantir un comportement fiable dans toutes les conditions.


### 5.1.2. Condensateur de filtrage C8 et C9

Immédiatement en aval du MOSFET Q1, deux condensateurs sont placés en parallèle sur la ligne VBAT. C8 est un condensateur électrolytique de 10 µF dont le rôle est de lisser les variations basses fréquences et d'absorber les pics de courant provenant de la batterie ou du câblage. C9 est un condensateur céramique de 100 nF qui prend en charge le filtrage des perturbations haute fréquence, notamment le bruit de commutation. L'association de ces deux valeurs permet de couvrir un large spectre de fréquences parasites et de présenter une alimentation propre aux étages suivants.

### 5.1.3. Module MPPT

Le TSR22450 constitue le cœur fonctionnel de la partie alimentation. Ce régulateur intègre un algorithme MPPT (Maximum Power Point Tracking) qui recherche en permanence le point de fonctionnement du panneau solaire offrant la puissance maximale, indépendamment des conditions d'ensoleillement ou de température. Il reçoit en entrée la tension délivrée par le panneau (~12 V via VBAT) et assure la recharge optimale de la batterie. Parce qu'il fonctionne en commutation, il génère des perturbations haute fréquence sur ses lignes d'alimentation ; c'est pourquoi deux condensateurs de découplage C7 et C9 (100 nF chacun) sont placés de part et d'autre du module pour les absorber et éviter qu'elles ne se propagent au reste du circuit.


### 5.1.4. Convertisseur analogique-numérique MCP3021


Le MCP3021 est également intégré à ce schéma. Il permet d'acquérir la tension de la batterie avec une précision supérieure à celle de l'ADC interne de l'ESP32, en communiquant avec ce dernier via le bus I2C. C'est cette mesure qui permet d'afficher l'état de charge de la batterie sur l'interface web.

### 5.1.5 LEDs indicatrices

Enfin, des LEDs sont présentes sur le schéma. Elles servent uniquement d'indicateurs visuels : quand une LED est allumée, ça confirme que la tension correspondante est bien présente sur la carte. C'est pratique lors des tests et de la mise au point pour vérifier d'un coup d'œil que l'alimentation fonctionne correctement.


## 5.2. Schéma Alimentation avant modification :


## 5.3. Routage final effectuer par Théo :


## 5.5. Mon routage :

# 6. Assemblage de la carte

## 6.1. Sérigraphie de la pâte à braser

Grâce aux installations de la licence CPSE, l'assemblage de la carte a pu être réalisé dans des conditions très proches d'un environnement industriel professionnel. La première étape a consisté à déposer la pâte à braser sur les pastilles du PCB à l'aide d'un pochoir métallique. Ce pochoir est une feuille d'acier découpée avec précision aux emplacements exacts des pastilles, ce qui garantit que la pâte se dépose uniquement aux endroits nécessaires, sans débordement sur les zones isolantes. La pâte est étalée à la raclette en un seul passage régulier pour obtenir des dépôts homogènes et d'épaisseur uniforme. Le port de gants est obligatoire durant cette manipulation car la pâte à braser contient des composés chimiques irritants au contact de la peau. Une fois le pochoir soigneusement retiré, on peut observer sur chaque pastille un petit dépôt de pâte grisâtre bien délimité, prêt à recevoir les composants.

## 6.2. Pose des composants

La pose des composants s'est déroulée en deux phases selon leur taille et leur précision de placement requise. Les composants passifs de petite taille, résistances et condensateurs CMS, ont été placés manuellement à l'aide d'une placeuse à aspiration. Cet outil fonctionne comme une pince pneumatique : une légère dépression maintient le composant en suspension au bout de l'embout, ce qui permet de le positionner délicatement sur les dépôts de pâte sans ne le déplacer ni le contaminer. Pour les composants plus grands et surtout plus exigeants en termes de précision de placement, comme l'ESP32 dont le pas des broches est très fin, la placeuse automatique Pick and Place a été utilisée. Les composants sont d'abord déposés manuellement à proximité, puis la machine les récupère, les centre optiquement et les pose avec une précision micrométrique qu'aucune intervention humaine directe ne pourrait atteindre de manière reproductible.

## 6.3. Refusion au four

Une fois l'ensemble des composants en place sur leurs dépôts de pâte, la carte a été introduite dans le four de refusion. Ce four applique un profil thermique précisément contrôlé, composé de plusieurs phases distinctes. La première phase est une montée progressive en température qui active le flux contenu dans la pâte à braser : ce flux a pour rôle de nettoyer chimiquement les surfaces métalliques et de les préparer à former des liaisons soudées de qualité. Vient ensuite le pic de température, typiquement autour de 250 °C pour un alliage sans plomb, qui fait fondre l'alliage de la pâte et crée les joints de soudure entre les broches des composants et les pastilles du PCB. Enfin, un refroidissement contrôlé permet à l'alliage de se solidifier progressivement en formant des soudures brillantes et mécaniquement solides, en évitant les contraintes thermiques qui pourraient fragiliser les joints ou endommager certains composants sensibles.

## 6.4. Inspection et contrôle qualité

À la sortie du four, chaque soudure a été inspectée visuellement à la loupe afin de détecter d'éventuels défauts. Les deux défauts les plus courants en refusion sont les ponts de soudure des courts-circuits involontaires entre deux broches adjacentes provoqués par un excès de pâte et les soudures froides, reconnaissables à leur aspect mat et granuleux, qui traduisent une mauvaise mouillabilité et une liaison électrique ou mécanique insuffisante. Des tests de continuité au multimètre ont ensuite été réalisés sur les connexions les plus critiques du circuit pour confirmer l'absence de coupures ou de court-circuit non détectés visuellement.

## 6.5. Mise sous tension et tests fonctionnels

Avant de procéder aux tests logiciels, la carte a d'abord été mise sous tension avec précaution pour vérifier que la consommation de courant se situait dans les valeurs attendues et qu'aucun composant ne chauffait anormalement, ce qui aurait pu signaler un problème de soudure ou un défaut de conception. Une fois ce premier contrôle validé, le firmware Micro Python a été flashé sur l'ESP32 et les tests fonctionnels ont été conduits de manière séquentielle, bloc par bloc. Le capteur Lidar, le driver du moteur pas-à-pas, la lecture de la tension batterie via le MCP3021 et le serveur web embarqué ont chacun été testés et validés indépendamment avant de passer au suivant. Cette méthode de validation progressive permet de localiser précisément l'origine d'un éventuel dysfonctionnement et d'éviter de chercher une panne dans l'ensemble du système en même temps.

# 7. Problèmes rencontrés

Sur la carte V1, nous avons rencontré plusieurs problèmes qui nous ont bien bloqués avant de réussir à tous les identifier. Certains étaient des erreurs de schéma, d'autres venaient des empreintes des composants.

### 7.1. Inversion des sorties moteur

La première erreur détectée concernait le câblage des sorties du driver moteur. Les sorties OUT1A et OUT1B avaient été inversées dans le schéma électrique, ce qui faisait tourner le moteur dans le sens opposé à celui attendu. Bien que cette erreur n'ait pas empêché la carte de fonctionner électriquement, elle rendait le comportement du système incohérent et aurait compromis le bon fonctionnement mécanique de l'ensemble. La correction a consisté à intervertir les deux connexions dans le schéma lors du passage en V2.

### 7.2. Oubli des underscores dans les labels ESP_RESET et ESP_BOOT

Les underscores avaient été oublié dans les noms des labels ESP_RESET et ESP_BOOT, ce qui empêchait le logiciel de reconnaître les liaisons correspondantes. Les broches se retrouvaient électriquement coupées, rendant la programmation de l'ESP32 impossible. Le diagnostic a pris du temps précisément parce que l'origine du problème était une simple faute de frappe dans un nom de net, ce qui a renforcé l'importance d'une relecture rigoureuse des labels avant toute opération de routage.

### 7.3. Broche non connectée sur le FT232RL

Le FT232RL assure la communication USB entre l'ordinateur et l'ESP32. Sur la V1, sa broche 18 n'était pas reliée au 3,3 V, ce qui rendait la connexion USB instable et la programmation peu fiable. Une fois le problème localisé à partir de la datasheet, la correction était directe : il suffisait d'ajouter la connexion manquante dans le schéma de la V2.

### 7.4. Court-circuit provoqué par une empreinte incorrecte sur l'UMH3NTN

L'UMH3NTN avait été créé manuellement dans la bibliothèque de composants du projet. Une erreur de correspondance entre les broches du schéma et celles de l'empreinte physique a provoqué un court-circuit à la mise sous tension. Ce type d'erreur est difficile à anticiper car il n'apparaît pas dans le schéma et ne se manifeste qu'à l'assemblage. Cela a conduit à adopter une vérification systématique de chaque composant créé sur mesure, en le comparant point par point avec la datasheet du fabricant.

### 7.5. Hétérogénéité des empreintes de résistances

Enfin, les résistances présentes sur la carte ne partageaient pas toutes la même empreinte, c'est-à-dire que leurs dimensions physiques variaient d'un composant à l'autre sur le PCB. Cette incohérence a compliqué l'étape de soudage, notamment lors de la sérigraphie de la pâte à braser et du placement des composants, car les gabarits et les réglages ne correspondaient pas uniformément à l'ensemble des résistances. Sur la V2, une harmonisation des empreintes a été réalisée pour garantir une cohérence dimensionnelle sur toute la carte et faciliter l'assemblage.

# 8. Conclusion

# 9. Annexes


Etalement de la pâte du le pochoir

Pose de la pâte a braser sur le pochoir


Image du PCB et de la pose de composants plus important

Pose des composants dans la station de placement


Image du placement du FT232RL avec la placeuse automatique


Placeuse automatique


Vérification des pins de certains composants

Image du four

22/23 DESCAMPS Anaël – Lycée Polyvalent Antoine Bourdelle BTS CIEL option ER

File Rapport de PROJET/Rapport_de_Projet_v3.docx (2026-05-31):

BTS CIEL 921

2025-2026

Anaël DESCAMPS

Rapport de Projet


# 1. Introduction

Dans le cadre de ma formation en BTS CIEL option ER, on nous a demandé de rédiger un rapport de projet individuel pour présenter le travail qu’on a réalisé tout au long de l’année.

Ce document fait suite au rapport commun intitulé “Rapport commun Pico-centrale hydroélectrique” et se concentre uniquement sur ma contribution personnelle dans ce projet. Pour rappel, l’association Viseta, basée dans les Hautes-Pyrénées, nous a confié la conception de l’électronique de contrôle de la vanne de décharge, qu’on appelle l’ECVD, pour équiper sa pico-centrale hydroélectrique. Le principe est simple : une turbine en vis d’Archimède est installée dans un ancien moulin abandonné, et notre système doit réguler automatiquement le niveau d’eau en amont de cette turbine. Pour ça, un capteur Lidar mesure la hauteur d’eau en continu, et en fonction de cette mesure, un moteur pas-à-pas ouvre ou ferme la vanne de décharge. Tout le système fonctionne de manière autonome grâce à une batterie 12V rechargée par un panneau solaire via un régulateur MPPT, ce qui évite d’avoir besoin d’une connexion au réseau électrique. C’est une solution bien adaptée pour des sites isolés comme des moulins en pleine campagne.

## 1.1. Remerciement

Avant de commencer, je voudrais remercier les personnes qui nous ont aidés et encadrés tout au long de ce projet. Sans leur suivi et leurs conseils, on n’aurait pas pu avancer aussi efficacement :

Toute l’équipe enseignante technique du lycée Antoine Bourdelle, pour les conseils qu’ils nous ont donnés et pour leur suivi régulier du projet, ce qui nous a vraiment permis d’avancer dans la bonne direction :

- M. ALARY

- M. HUART

- M. HAAS

## 1.2. Partie Personnel

Dans le cadre du projet PICO centrale, j'ai travaillé principalement sur deux aspects : la supervision de la batterie et la conception de l'interface homme-machine (IHM) sous forme de page web embarquée. Ces deux parties sont étroitement liées, dans la mesure où l'IHM affiche en temps réel l'état de la batterie, des panneaux solaires connectés via le module MPPT, ainsi que les données transmises par le capteur de niveau d'eau. L'ensemble permet à l'opérateur de surveiller le système aisément depuis son téléphone.

### 1.2.1. Analyse des besoins énergétiques

J'ai débuté par l'analyse des besoins énergétiques du système, étape incontournable : une sous-estimation de la consommation risquerait de compromettre l'autonomie de la batterie la nuit ou par temps couvert. J'ai donc élaboré un tableau Excel recensant, d'une part, la consommation théorique maximale de chaque module, et d'autre part, les valeurs mesurées expérimentalement, en distinguant trois états de fonctionnement : mode actif, repos et veille profonde. Cette comparaison a permis d'évaluer l'écart entre les spécifications fabricant et la consommation réelle, d'identifier les éléments les plus énergivores — le moteur pas-à-pas en premier lieu — et de confirmer l'adéquation de la batterie retenue. J'ai également tracé la courbe d'évolution du courant du moteur pas-à-pas en fonction de sa vitesse, afin d'analyser l'impact de la vitesse de déplacement de la vanne sur la consommation et d'ajuster les paramètres du driver en conséquence.

### 1.2.2. Vérification et saisie de la partie alimentation

J'ai ensuite pris en charge la vérification et la saisie de la partie alimentation du projet. Bien que le schéma de base ait été fourni par l'enseignant, j'ai procédé à une vérification et un recalcul des valeurs des composants afin de m'assurer de leur cohérence avec les exigences du système. J'ai notamment recalculé les valeurs des résistances du diviseur de tension utilisé pour la mesure de la batterie via l'ADC de l'ESP32, ainsi que celles des condensateurs de filtrage. J'ai ensuite réalisé la saisie du schéma et le routage de ma section sur Proteus, en veillant à bien séparer les plans de masse numérique et de puissance, afin d'éviter que les perturbations générées par les étages de puissance ne viennent affecter les signaux analogiques, notamment la mesure de tension de la batterie.

### 1.2.3. Intégration et validation du module MPPT

J'ai également assuré l'intégration et la validation du module MPPT couplé au panneau photovoltaïque, qui constitue la source d'énergie principale du système. J'ai vérifié les tensions en sortie du régulateur dans différentes conditions de fonctionnement, mesuré le courant de charge réel, et mis en œuvre dans le code la lecture de la tension batterie via l'ADC de l'ESP32. Ces éléments ont permis de valider l'autonomie énergétique du système sur plusieurs cycles de charge et de décharge.

### 1.2.4. Interface homme-machine (IHM)

Enfin, j'ai participé à la conception et à l'intégration de l'interface utilisateur. Cette page web s'exécute directement sur l'ESP32, sans recours à un serveur externe. Elle est accessible via un réseau Wi-Fi généré par l'ESP32 lui-même, auquel il est possible de se connecter directement depuis un téléphone, sans nécessiter de box ou d'accès Internet. La page affiche la hauteur d'eau, l'état de la batterie, le courant solaire et la position de la vanne, et offre à l'opérateur la possibilité de modifier la consigne de niveau d'eau à distance. L'ensemble a été intégré dans le programme final en Micro Python. J'ai par ailleurs développé un programme de test modulaire permettant de valider chaque sous-ensemble indépendamment avant l'assemblage final, ce qui a facilité l'identification et l'isolation des dysfonctionnements.

### 1.2.5. Bilan

Ce projet m'a permis d'intervenir sur des domaines variés : bilan de consommation, vérification de schémas, routage PCB, développement en Micro Python et conception d'une interface web embarquée. La principale valeur ajoutée de cette expérience réside dans la conduite d'un système électronique complet et autonome de bout en bout, en prenant en compte simultanément les contraintes énergétiques, logicielles et matérielles — une approche globale rarement aussi concrète dans le cadre des enseignements habituels.


## 1.3. Diagrammes


# 2. Mesure et calcul de la tension

Pour commencer, j’ai mesuré la consommation de chaque composant qui risquait de tirer beaucoup de courant, pour vérifier si la batterie initialement prévue était suffisante ou s’il fallait la changer. C’est une étape importante parce que si on se trompe à ce stade, tout le dimensionnement de l’alimentation est faux. J’ai donc fait un tableau Excel, visible ci-dessous, avec pour chaque composant sa consommation maximale, sa consommation au repos, et la valeur théorique indiquée dans sa datasheet. Ça permet de comparer ce que le fabricant annonce avec ce qu’on mesure réellement.


J’ai aussi relevé l’évolution du courant consommé par le moteur pas-à-pas selon sa vitesse. Pour ça, j’ai utilisé le moteur de remplacement que le prof nous a prêté, en attendant le moteur définitif prévu pour le projet, qui est plus puissant, étanche et avec un couple plus élevé. Les mesures montrent que la consommation monte avec la vitesse, ce qui est logique, mais elle finit par se stabiliser à partir d’un certain seuil. Ces infos sont utiles pour régler le driver moteur et éviter de consommer de l’énergie pour rien

# 3. Création du site et assemblage des codes

Pour cette partie, j’ai créé une page web hébergée directement sur l’ESP32. Elle affiche en temps réel la hauteur d’eau mesurée par le Lidar, la tension de la batterie en volts, et le courant produit ou consommé par le panneau solaire. Pour la partie mesure du niveau d’eau, j’ai récupéré et adapté le code de Jessy dans mon programme, ce qui m’a demandé un peu de travail pour harmoniser les deux codes et faire en sorte que tout fonctionne ensemble sans conflit


La page est pensée pour être consultée depuis un téléphone. L’ESP32 crée son propre réseau Wi-Fi, donc l’opérateur n’a qu’à s’y connecter directement sur le site, sans avoir besoin d’une connexion internet ou d’une box. C’est un vrai plus pour une installation en pleine nature comme un moulin isolé. On a également mis en place une connexion vers ThingSpeak, un service en ligne qui permet d’enregistrer et de visualiser des données sous forme de courbes. Les données sont envoyées toutes les 15 secondes, ce qui correspond au délai minimum proposé par la version gratuite du service. Ça nous permet de suivre l’évolution du niveau d’eau et de détecter d’éventuels problèmes même à distance.


# 3.1. Algorigrammes 4. Saisie de Schéma

## 4.1. Saisie du schéma et routage

À partir du schéma fourni par l'enseignant, nous avons procédé à la saisie sur Proteus 8 avant d'effectuer le routage. Théo et moi avons chacun réalisé notre propre version, et c'est celle de Théo qui a été retenue, car il l'a finalisée en premier. Cette étape s'est révélée particulièrement répétitif : lors des revues de conception, le professeur a relevé plusieurs erreurs qui ont nécessité des corrections répétées. Bien que contraignant, ce processus nous a permis d'assimiler les règles fondamentales du routage : la séparation rigoureuse des plans de masse, le dimensionnement adapté des pistes de puissance, le placement des condensateurs de découplage au plus près des circuits intégrés, etc.

La figure ci-dessous présente le schéma de la partie alimentation que j'ai réalisée, dont je détaillerai les différents blocs dans la suite.

### 4.1.1. Protection contre l'inversion de polarité

Le composant le plus critique de ce schéma est le MOSFET canal P Q1, référencé FDD4141, placé directement en entrée entre la batterie (VBAT) et le reste du circuit. Son rôle est d'assurer une protection totale contre un branchement incorrect de la batterie.


Un MOSFET canal P conduit lorsque sa tension grille-source (Vgs) est négative, lorsque la grille est à un potentiel inférieur à celui de la source. En fonctionnement normal, la résistance R17 (47 kΩ) tire la grille à un potentiel bas, ce qui rend Vgs suffisamment négatif pour ouvrir le canal et laisser circuler librement le courant depuis la batterie vers le reste du circuit. En revanche, si la batterie est branchée à l'envers, Vgs devient positif, le canal se bloque immédiatement et aucun courant ne peut traverser le circuit tous les composants en aval se trouvent ainsi protégés. Le composant U10 (LM4040), une référence de tension de précision de type Zener shunt, contribue à stabiliser la tension de commande de la grille pour garantir un comportement fiable dans toutes les conditions.

### 4.1.2. Condensateur de filtrage C8 et C9

Immédiatement en aval du MOSFET Q1, deux condensateurs sont placés en parallèle sur la ligne VBAT. C8 est un condensateur électrolytique de 10 µF dont le rôle est de lisser les variations basses fréquences et d'absorber les pics de courant provenant de la batterie ou du câblage. C9 est un condensateur céramique de 100 nF qui prend en charge le filtrage des perturbations haute fréquence, notamment le bruit de commutation. L'association de ces deux valeurs permet de couvrir un large spectre de fréquences parasites et de présenter une alimentation propre aux étages suivants.

### 4.1.3. Module MPPT

Le TSR22450 constitue le cœur fonctionnel de la partie alimentation. Ce régulateur intègre un algorithme MPPT (Maximum Power Point Tracking) qui recherche en permanence le point de fonctionnement du panneau solaire offrant la puissance maximale, indépendamment des conditions d'ensoleillement ou de température. Il reçoit en entrée la tension délivrée par le panneau (~12 V via VBAT) et assure la recharge optimale de la batterie. Parce qu'il fonctionne en commutation, il génère des perturbations haute fréquence sur ses lignes d'alimentation ; c'est pourquoi deux condensateurs de découplage C7 et C9 (100 nF chacun) sont placés de part et d'autre du module pour les absorber et éviter qu'elles ne se propagent au reste du circuit.

### 4.1.4. Convertisseur analogique-numérique MCP3021


Le MCP3021 est également intégré à ce schéma. Il permet d'acquérir la tension de la batterie avec une précision supérieure à celle de l'ADC interne de l'ESP32, en communiquant avec ce dernier via le bus I2C. C'est cette mesure qui permet d'afficher l'état de charge de la batterie sur l'interface web.

### 4.1.5 LEDs indicatrices


Enfin, des LEDs sont présentes sur le schéma. Elles servent uniquement d'indicateurs visuels : quand une LED est allumée, ça confirme que la tension correspondante est bien présente sur la carte. C'est pratique lors des tests et de la mise au point pour vérifier d'un coup d'œil que l'alimentation fonctionne correctement.

## 4.2. Schéma Alimentation avant modification :


## 4.3. Routage final effectuer par Théo :


## 4.5. Mon routage :

# 5. Assemblage de la carte

## 5.1. Sérigraphie de la pâte à braser

Grâce aux installations de la licence CPSE, l'assemblage de la carte a pu être réalisé dans des conditions très proches d'un environnement industriel professionnel. La première étape a consisté à déposer la pâte à braser sur les pastilles du PCB à l'aide d'un pochoir métallique. Ce pochoir est une feuille d'acier découpée avec précision aux emplacements exacts des pastilles, ce qui garantit que la pâte se dépose uniquement aux endroits nécessaires, sans débordement sur les zones isolantes. La pâte est étalée à la raclette en un seul passage régulier pour obtenir des dépôts homogènes et d'épaisseur uniforme. Le port de gants est obligatoire durant cette manipulation car la pâte à braser contient des composés chimiques irritants au contact de la peau. Une fois le pochoir soigneusement retiré, on peut observer sur chaque pastille un petit dépôt de pâte grisâtre bien délimité, prêt à recevoir les composants.

## 5.2. Pose des composants

La pose des composants s'est déroulée en deux phases selon leur taille et leur précision de placement requise. Les composants passifs de petite taille, résistances et condensateurs CMS, ont été placés manuellement à l'aide d'une placeuse à aspiration. Cet outil fonctionne comme une pince pneumatique : une légère dépression maintient le composant en suspension au bout de l'embout, ce qui permet de le positionner délicatement sur les dépôts de pâte sans ne le déplacer ni le contaminer. Pour les composants plus grands et surtout plus exigeants en termes de précision de placement, comme l'ESP32 dont le pas des broches est très fin, la placeuse automatique Pick and Place a été utilisée. Les composants sont d'abord déposés manuellement à proximité, puis la machine les récupère, les centre optiquement et les pose avec une précision micrométrique qu'aucune intervention humaine directe ne pourrait atteindre de manière reproductible.

## 5.3. Refusion au four

Une fois l'ensemble des composants en place sur leurs dépôts de pâte, la carte a été introduite dans le four de refusion. Ce four applique un profil thermique précisément contrôlé, composé de plusieurs phases distinctes. La première phase est une montée progressive en température qui active le flux contenu dans la pâte à braser : ce flux a pour rôle de nettoyer chimiquement les surfaces métalliques et de les préparer à former des liaisons soudées de qualité. Vient ensuite le pic de température, typiquement autour de 250 °C pour un alliage sans plomb, qui fait fondre l'alliage de la pâte et crée les joints de soudure entre les broches des composants et les pastilles du PCB. Enfin, un refroidissement contrôlé permet à l'alliage de se solidifier progressivement en formant des soudures brillantes et mécaniquement solides, en évitant les contraintes thermiques qui pourraient fragiliser les joints ou endommager certains composants sensibles.

## 5.4. Inspection et contrôle qualité

À la sortie du four, chaque soudure a été inspectée visuellement à la loupe afin de détecter d'éventuels défauts. Les deux défauts les plus courants en refusion sont les ponts de soudure — des courts-circuits involontaires entre deux broches adjacentes provoqués par un excès de pâte — et les soudures froides, reconnaissables à leur aspect mat et granuleux, qui traduisent une mauvaise mouillabilité et une liaison électrique ou mécanique insuffisante. Des tests de continuité au multimètre ont ensuite été réalisés sur les connexions les plus critiques du circuit pour confirmer l'absence de coupures ou de court-circuit non détectés visuellement.

## 5.5. Mise sous tension et tests fonctionnels

Avant de procéder aux tests logiciels, la carte a d'abord été mise sous tension avec précaution pour vérifier que la consommation de courant se situait dans les valeurs attendues et qu'aucun composant ne chauffait anormalement, ce qui aurait pu signaler un problème de soudure ou un défaut de conception. Une fois ce premier contrôle validé, le firmware Micro Python a été flashé sur l'ESP32 et les tests fonctionnels ont été conduits de manière séquentielle, bloc par bloc. Le capteur Lidar, le driver du moteur pas-à-pas, la lecture de la tension batterie via le MCP3021 et le serveur web embarqué ont chacun été testés et validés indépendamment avant de passer au suivant. Cette méthode de validation progressive permet de localiser précisément l'origine d'un éventuel dysfonctionnement et d'éviter de chercher une panne dans l'ensemble du système en même temps.

# 6. Problèmes rencontrés

### Sur la carte V1, nous avons rencontré plusieurs problèmes qui nous ont bien bloqués avant de réussir à tous les identifier. Certains étaient des erreurs de schéma, d'autres venaient des empreintes des composants.

### 6.1. Inversion des sorties moteur

La première erreur détectée concernait le câblage des sorties du driver moteur. Les sorties OUT1A et OUT1B avaient été inversées dans le schéma électrique, ce qui faisait tourner le moteur dans le sens opposé à celui attendu. Bien que cette erreur n'ait pas empêché la carte de fonctionner électriquement, elle rendait le comportement du système incohérent et aurait compromis le bon fonctionnement mécanique de l'ensemble. La correction a consisté à intervertir les deux connexions dans le schéma lors du passage en V2.

### 6.2. Oubli des underscores dans les labels ESP_RESET et ESP_BOOT

Cette erreur a été la plus bloquante. Les underscores avaient été oublié dans les noms des labels ESP_RESET et ESP_BOOT, ce qui empêchait le logiciel de reconnaître les liaisons correspondantes. Les broches se retrouvaient électriquement coupées, rendant la programmation de l'ESP32 impossible. Le diagnostic a pris du temps précisément parce que l'origine du problème était une simple faute de frappe dans un nom de net, ce qui a renforcé l'importance d'une relecture rigoureuse des labels avant toute opération de routage.

### 6.3. Broche non connectée sur le FT232RL

Le FT232RL assure la communication USB entre l'ordinateur et l'ESP32. Sur la V1, sa broche 18 n'était pas reliée au 3,3 V, ce qui rendait la connexion USB instable et la programmation peu fiable. Une fois le problème localisé à partir de la datasheet, la correction était directe : il suffisait d'ajouter la connexion manquante dans le schéma de la V2.

### 6.4. Court-circuit provoqué par une empreinte incorrecte sur l'UMH3NTN

L'UMH3NTN avait été créé manuellement dans la bibliothèque de composants du projet. Une erreur de correspondance entre les broches du schéma et celles de l'empreinte physique a provoqué un court-circuit à la mise sous tension. Ce type d'erreur est difficile à anticiper car il n'apparaît pas dans le schéma et ne se manifeste qu'à l'assemblage. Cela a conduit à adopter une vérification systématique de chaque composant créé sur mesure, en le comparant point par point avec la datasheet du fabricant.

### 6.5. Hétérogénéité des empreintes de résistances

Enfin, les résistances présentes sur la carte ne partageaient pas toutes la même empreinte, c'est-à-dire que leurs dimensions physiques variaient d'un composant à l'autre sur le PCB. Cette incohérence a compliqué l'étape de soudage, notamment lors de la sérigraphie de la pâte à braser et du placement des composants, car les gabarits et les réglages ne correspondaient pas uniformément à l'ensemble des résistances. Sur la V2, une harmonisation des empreintes a été réalisée pour garantir une cohérence dimensionnelle sur toute la carte et faciliter l'assemblage.

# 7. Conclusion

# 8. Annexes


Etalement de la pâte du le pochoir

Pose de la pate a braser sur le pochoir


Image du PCB et de la pose de composants plus important

Pose des composants dans la station de placement


Image du placement du FT232RL avec la placeuse automatique


Placeuse automatique


Image du four

Vérification des pins de certains composants

2/19 DESCAMPS Anaël – Lycée Polyvalent Antoine Bourdelle BTS CIEL option ER

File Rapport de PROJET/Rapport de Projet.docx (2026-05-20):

Lycée Antoine Bourdelle | LinkedIn

BTS CIEL 921

2025-2026

Anaël DESCAMPS

Rapport de Projet


# 1. Introduction

Dans le cadre de ma formation, il m’a été demandé de réaliser un rapport de fin de projet.

Ce document fait suite au document intitulé “Rapport commun Pico-centrale hydroélectrique”, il traitera de la partie du travail personnel effectué par Descamps Anaël lors du développement du projet. Pour rappel, l’association Viseta, située dans les Hautes-Pyrénées, nous a confié la conception de l’électronique de contrôle de la vanne de décharge (ECVD) pour sa pico-centrale hydroélectrique. C’est un système innovant conçu pour réguler automatiquement le niveau d’eau d’une turbine en vis d’Archimède installée dans d’anciens moulins abandonnés. Grâce à un capteur Lidar intégré, il ajuste la position d’un moteur pas-à-pas en fonction des mesures de hauteur d’eau, garantissant ainsi une production d’électricité locale plus stable, autonome (via batterie 12V + PV/MPPT) et respectueuse de la biodiversité.

## 1. 1.Remerciement

Avant de commencer, je souhaite faire une mention à toutes les personnes qui m’ont permis de réaliser ce projet dans de bonnes conditions :

L’ensemble de l’équipe technique enseignante du lycée Antoine Bourdelle pour les nombreux conseils précieux qu’ils nous ont donnés ainsi que pour leur suivi de projet très régulier permettant à l’ensemble du groupe d’avancer de manière certaine :

- M. ALARY

- M. HUART

- M. HAAS

## 1. 2. Partie Personelle

Dans le cadre du projet PICO centrale, j’ai participé à la conception et au développement de la partie supervision de la batterie et de l’interface homme-machine (IHM). Ce projet avait pour objectif de concevoir un système autonome alimenté par une source photovoltaïque, capable de surveiller la charge de la batterie et de piloter différents sous-systèmes via une page Web intégrée.

Tout d’abord, j’ai commencé par l’analyse des besoins énergétiques du système. Pour cela, j’ai établi un tableau Excel répertoriant la consommation théorique maximale de chaque module, ainsi que les valeurs mesurées en mode actif, repos et veille profonde. Cette étude m’a permis d’évaluer précisément l’autonomie du système et d’identifier les éléments les plus consommateurs d’énergie. J’ai également réalisé la courbe d’évolution du courant du moteur pas à pas en fonction de sa vitesse, afin de mieux comprendre son impact sur la consommation globale.

Ensuite, j’ai contribué à la mise en place de la partie alimentation du projet. Le schéma électrique de départ nous a été fourni, j’ai ce pendant revérifié et recalculé les valeurs des composants du circuit d’alimentation pour m’assurer de leur cohérence avec les spécifications techniques. Par la suite, j’ai effectué la saisie du schéma et le routage de la section concernée, en veillant à isoler correctement les plans de masse et d’alimentation pour garantir la stabilité du système.

Une autre partie essentielle de mon travail a consisté à intégrer le module MPPT et le panneau photovoltaïque, ainsi qu’à valider l’autonomie énergétique de l’ensemble. Cette phase a nécessité plusieurs vérifications du fonctionnement du régulateur de charge et des tensions mesurées sur la batterie rechargeable.

Enfin, j’ai participé à la mise en place de l’interface utilisateur (IHM). Celle-ci est accessible depuis une page Web hébergée par le contrôleur principal. Elle permet de visualiser l’état du système ECDV (niveau d’eau, tension, production solaire, etc.) et de modifier la consigne de niveau d’eau en temps réel. J’ai également intégré l’ensemble de ces fonctionnalités dans le programme final, incluant un programme de test pour vérifier le bon fonctionnement de chaque partie avant la validation complète du système.

Ce projet m’a permis de développer des compétences techniques variées : gestion énergétique, conception de schémas, routage, instrumentation et développement d’interfaces Web embarquées. Il a surtout renforcé ma capacité à travailler sur un système électronique complet, depuis l’analyse fonctionnelle jusqu’aux essais de validation.

## 2. Mesure et calcul de la tension

Tout d’abord j’ai commencé par la mesure de chaque gros composant susceptible de consommé un grand nombre d’ampère pour savoir si la batterie proposer était suffisante et s’il ne fallait pas la modifier.
J’ai donc créer un tableau sur Excel vu ci-dessous avec notamment les composant en consommation max et au repos avec aussi la consommation théorique écrit sur les datasheet


Ensuite j’ai aussi mesuré l’évolution du courant utiliser par le moteur en fonction de sa vitesse avec le moteur de remplacement donné par le prof en attendant le nouveau prevu pour le projet qui est plus puissant étanche et plus de couple

## 3. Création du site et assemblage des codes

Pour cette partie j’ai fait un site internet simple avec les valeurs en temps réels de la hauteur d’eau mesurer avec le capteur pour ça j’ai assemblé mon site avec le code de Jessy qui mesure la hauteur d’eau grâce au capteur, ensuite j’ai aussi mis la batterie avec les volts qui restent et les ampères récupérer ou générer par le panneau solaire

Le site est adapté pour téléphone pour que l’opérateur puisse y accéder facilement depuis un point wifi créer par l’esp de la carte


## 4. Saisie de Schéma

Ensuite en partant du schéma du prof on l’a recréé sur Proteus puis fait le routage, nous sommes deux à l’avoir fait Théo et moi, on a gardé celui de Théo tout simplement car il a fini en premier. On a pris pas mal de retard sur cette étape du projet car plusieurs fois pendant la création du PCB le prof c’est rendu compte de plusieurs erreurs qu’on a du ensuite modifier.


2/ DESCAMPS Anaël – Lycée Polyvalent Antoine Bourdelle BTS CIEL option ER

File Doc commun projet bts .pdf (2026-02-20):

### Pour l’étudiant n°5 : (Descamps Anaël)

1) Mesure de la tension de la batterie rechargeable
Concevoir la chaîne de mesure permettant de surveiller en continu la tension de la batterie 12 V, via un pont diviseur et une entrée analogique du microcontrôleur. Cette fonction permet d’évaluer l’état de charge, de détecter les sous-tensions ou surtensions.
2) Mise en place du module MPPT et du panneau photovoltaïque et validation de l’autonomie
Il s’agit d’intégrer le panneau photovoltaïque et le régulateur de charge de type MPPT afin de recharger efficacement la batterie dans des conditions d’ensoleillement variables. Vérifier, par mesures et essais, que la production solaire et la capacité de la batterie permettent au système ECVD de fonctionner de manière autonome sur la durée, en tenant compte des consommations des différents sous-systèmes.
3) Saisie de schéma et routage de la partie concernée du projet Réalisation du schéma électronique de la partie “alimentation et supervision batterie/MPPT”, puis de son routage sur un circuit imprimé. Cela implique le respect des règles de conception et la préparation des fichiers nécessaires à la fabrication de la carte.
4) Programme de test
Développer des programmes de test dédiés à la mesure de la tension batterie, au fonctionnement du MPPT et à la remontée d’informations vers le contrôleur. Ces programmes permettent de vérifier le bon câblage, la cohérence des mesures, le comportement en charge et les réactions du système en conditions.
5) Réalisation de l’IHM via une page Web fournie par le contrôleur principal (état du système ECDV et choix de la consigne du niveau d’eau)
Concevoir l’interface Homme–Machine accessible via une page Web, qui affiche l’état du système et permet de régler la consigne de niveau d’eau. Cette IHM doit être claire, lisible et adaptée à une utilisation à distance, en distinguant les droits d’un simple utilisateur et ceux d’un administrateur.
6) Intégration des différentes fonctions dans le programme final Enfin, intégrer l’ensemble de ses fonctionnalités dans le logiciel global du contrôleur principal ou local, suivant l’architecture définie. Cette étape nécessite une mise en cohérence avec les autres parties du projet, la gestion des ressources du microcontrôleur et la vérification du bon fonctionnement global lors des essais système.


Schéma Partie 5 :
Diode D2 pas obligatoire si branché au 12V car D1 existe


Optionnel

Partie 1 (régulateur RPM 5.0-6.0):


Regarder Fuel gauge I2C 12V pour MCP surveillance de la batterie
Etude partie MCP schéma
TSR 1A
Pont diviseur R1 et R2 + LED : V gain = 12*(10/(33+10)) = 2.88V R3 = 8.2kΩ -> courant LED ≈ 0.1mA

Régulateur U1 :

STEPPERONLINE Moteur pas a pas Nema 17 Bipolaire
Courant nominal : Généralement entre 1.5A et 2.0A par phase.

Courant : Contrairement à un moteur classique, la tension affichée (ex: 3.6V) n'est pas celle de votre alimentation, mais celle calculée par la loi d'Ohm,
(U = R \times I). En pratique, on utilise souvent des alimentations de 12V ou 24V.



While true qui se ferme

Ne pas clôturer

Ne pas bloqué le composant

Treas

Vérifier ouvrir connexion (accept) et ne pas fermer tant qu’il y a un utilisateur

Tache qui automatiquement refresh

Je veux que le système reste connecter et que la page se refresh toute les 2 sec et que au bout de 5 sec sans rien la boucle se ferme

## ROUTAGE :

NE PAS OUBLIER ROUTAGE PIN SENSE C5 5V a mettre a l’opposé de la carte


Lors du routage brancher chaque branche des condos en étoiles comme présentés sur la Figure 6.

Tableau : (consommation global du projet)estimation->câbler/mesurer 5 colonnes
appareil-état(travail-repos-veille profonde)-consommation esp32-point d'accès WIFI activé 1 utilisateur-

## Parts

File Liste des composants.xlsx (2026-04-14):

Ref | Descripton | Order code | Quantité | Site
629105150521 | USB | 2470822 | 1 | Farnell
AP781-33Y-13 | Diode | 3483002 | 1 | Farnell
KP-2012LSGC | KINGBRIGHT | 2463991 | 2 | Farnell
KP-2012LSYCK | KINGBRIGHT | 2463991 | 1 | Farnell
10BQ015 |  |  | 2 | Pas sur Farnell
MKDSN2_5 |  |  | 1 | Pas sur Farnell | Ref prof | 4179098
IRLML6344TRPBF | INFINEON | 1857299RL | 1 | Farnell | nok | FDDD4141
MCP3021A0T
MCP3021A1T
MCP3021A2T | MICROCHIP | 3796961 | 1 | Farnell
TSR 2-2450 | TRACO POWER | 2848984 | 1 | Farnell
AZ1117CR-3 | DIODES INC | 3483076 | 1 | Farnell
MCP3021A5T-E/OT | MICROCHIP | 1332097 | 2 | Farnell
MAX22204ATU+ | ANALOG DEVICES | 3929030 | 1 | Farnell
LORA E32-900T30D |  |  | 1 | Pas sur Farnell | Dejà ok
M5STAMP-SIM7080G |  |  | 1 | Pas sur Farnell | Déjà ok
ICS_TMUX1136DGSR |  |  | 1 | Pas sur Farnell | plus sur schéma
UMH3NTN | ROHM | 1680404 | 1 | Farnell
Vérifier condo | C1, C8, C10, C11, C17, C12, C13, C14, C16
Dispo chez farnell, valeur et tension de service
C1, C13, C16 | Multicomp PRO | 1759483 | 1 | Farnell
C8 | KYOCERA AVX | 197130 | 1 | Farnell
C10, C11 | KEMET | 4312864 | 2 | Farnell
C17 | Yageo | 3873527 | 5 | Farnell
C12,C14 | KYOCERA AVX | 1432414 | 2 | Farnell

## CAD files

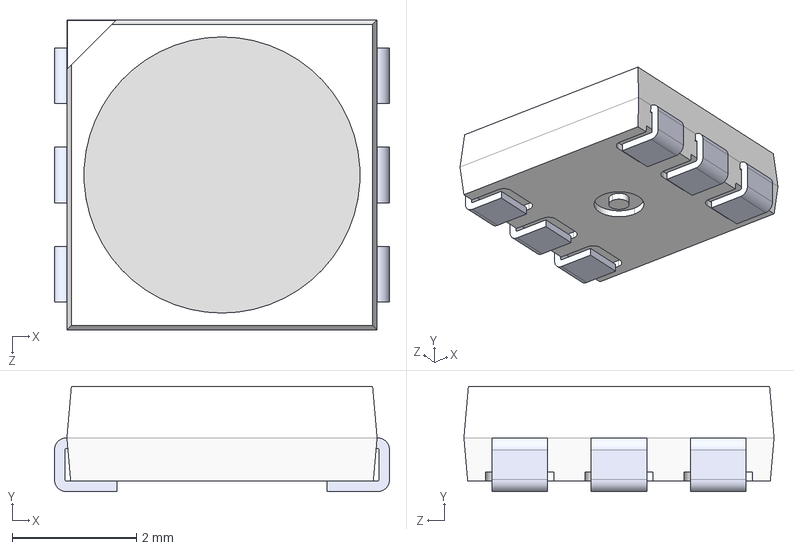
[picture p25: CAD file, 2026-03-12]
Schéma Proteus/Modèles 3D/WS2813.STEP
5.40 x 1.70 x 5.00 mm

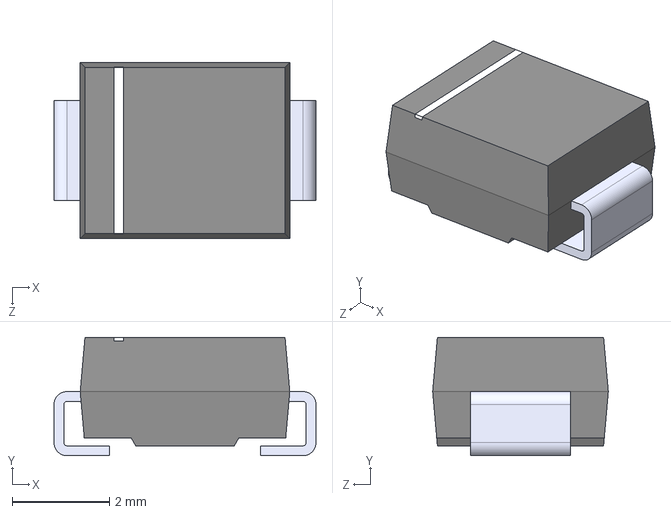
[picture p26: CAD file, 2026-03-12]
Schéma Proteus/Modèles 3D/SSB43.STEP
5.40 x 2.44 x 3.62 mm

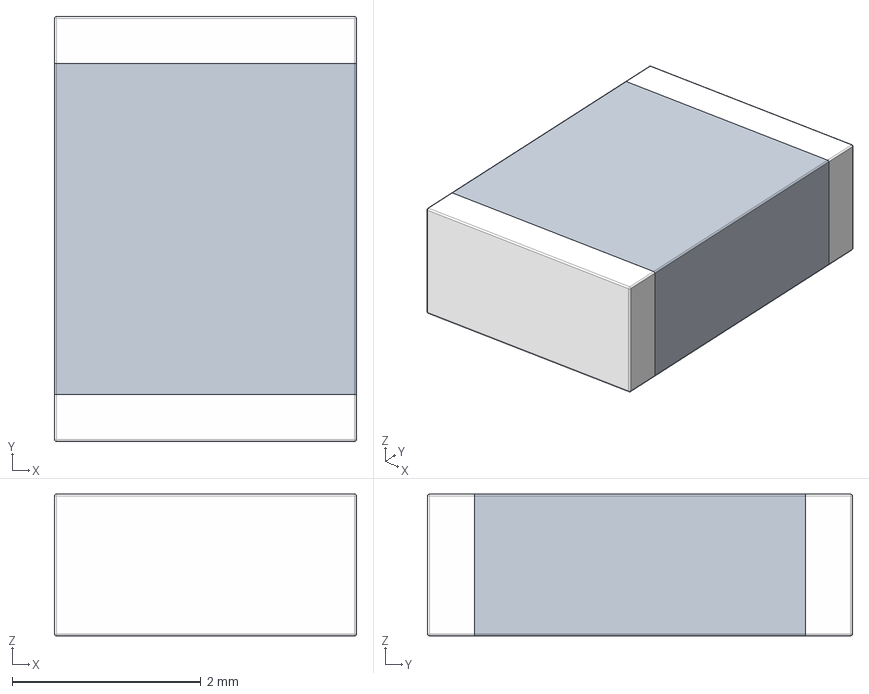
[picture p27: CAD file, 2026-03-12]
Schéma Proteus/Modèles 3D/WE-CBF_1812.step
3.20 x 4.50 x 1.50 mm

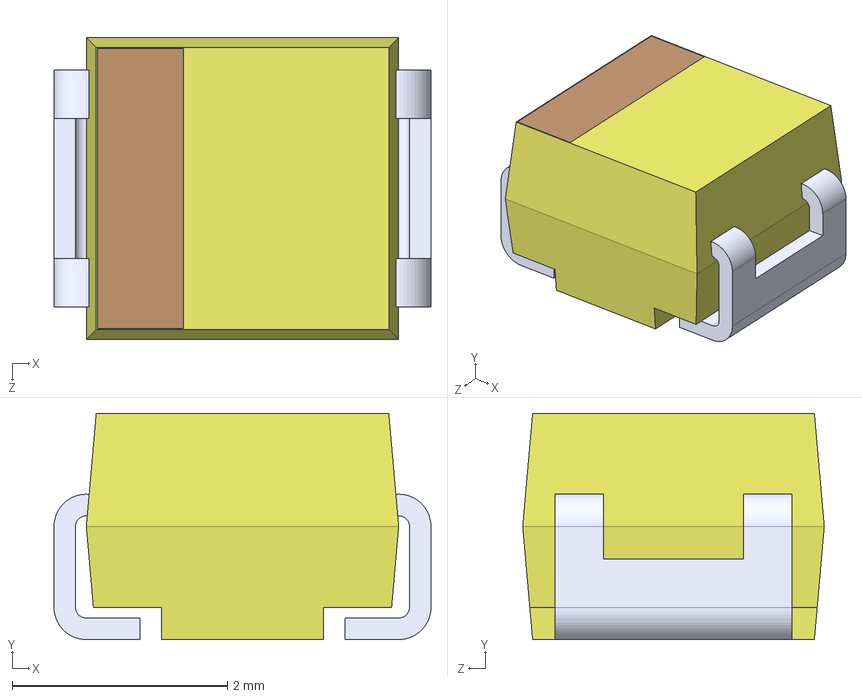
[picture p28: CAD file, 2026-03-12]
Schéma Proteus/Modèles 3D/TAJB106K025RNJ.step
3.50 x 2.10 x 2.80 mm

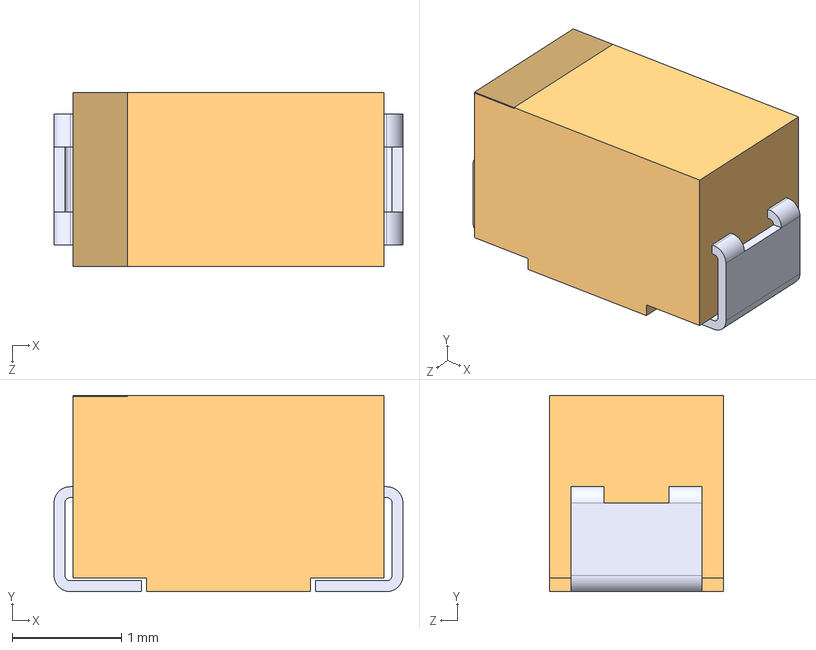
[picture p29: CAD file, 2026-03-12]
Schéma Proteus/Modèles 3D/TAJA106K010RNJ.step
3.20 x 1.80 x 1.60 mm

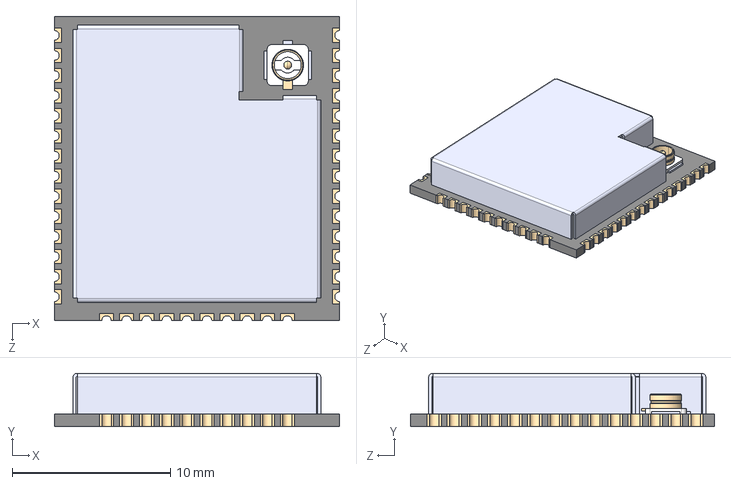
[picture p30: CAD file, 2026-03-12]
Schéma Proteus/Modèles 3D/ESP32-WROOM-32U.step
18.0 x 3.35 x 19.2 mm

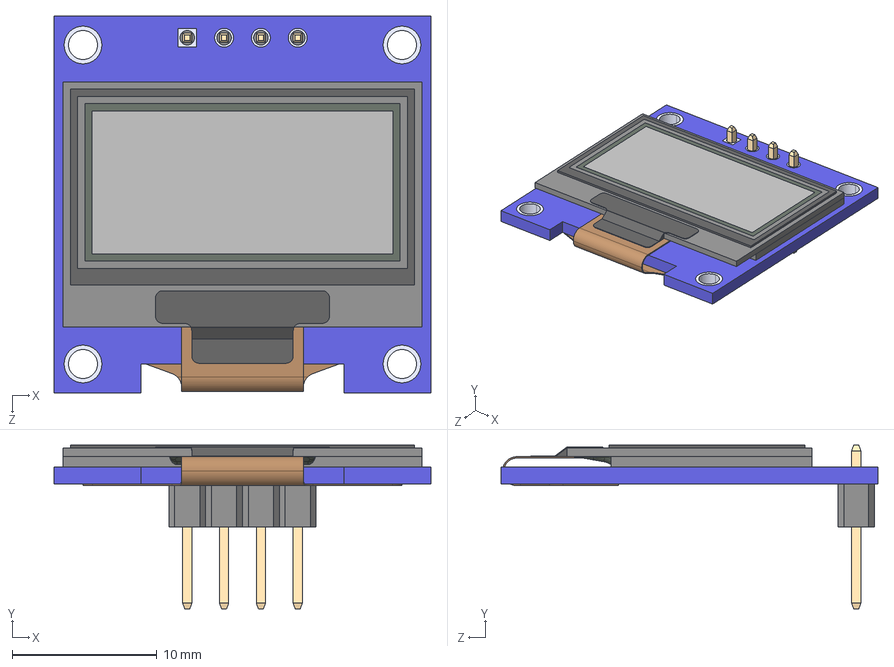
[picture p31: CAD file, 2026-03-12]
Schéma Proteus/Modèles 3D/DM-OLED096-636.step
26.0 x 11.3 x 26.0 mm
DM-OLED096-636_Module
DM-OLED096-636_Panel

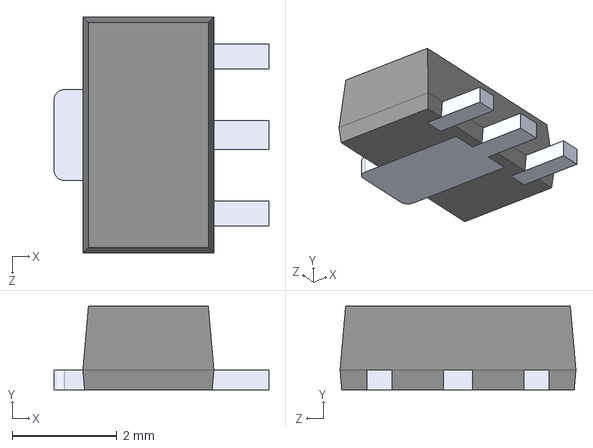
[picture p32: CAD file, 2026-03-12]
Schéma Proteus/Modèles 3D/AZ1117CR-3.3TRG1.step
4.10 x 1.60 x 4.50 mm

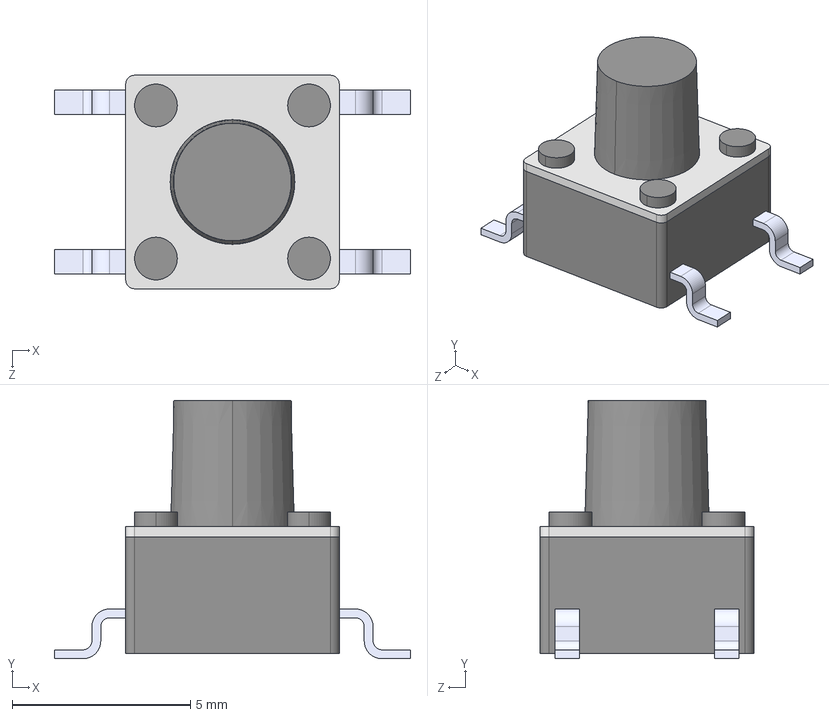
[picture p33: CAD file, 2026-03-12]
Schéma Proteus/Modèles 3D/4-1437565-9.step
10.0 x 7.26 x 6.00 mm

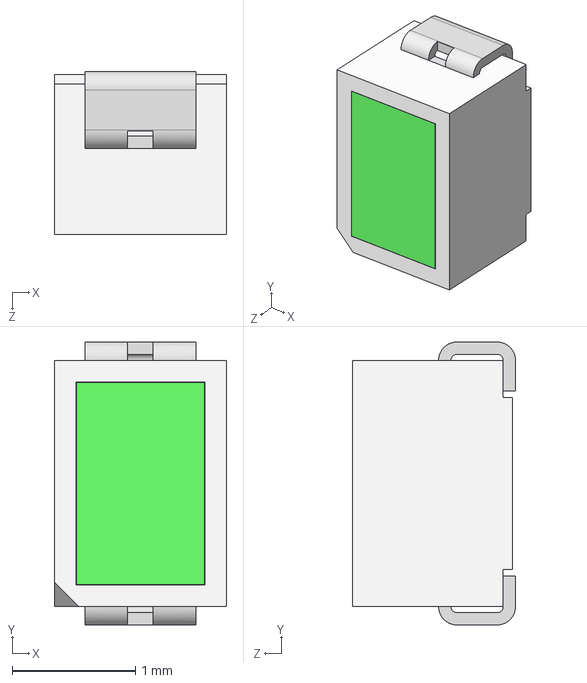
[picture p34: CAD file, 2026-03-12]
Schéma Proteus/Modèles 3D/LG M67K TOPLED Green-1.step
1.40 x 2.30 x 1.33 mm

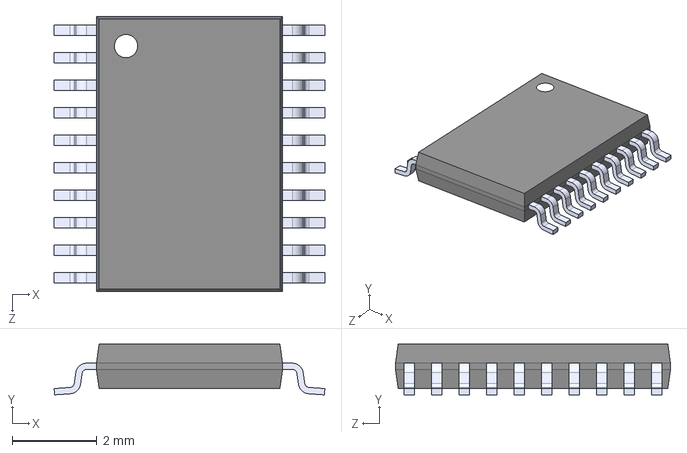
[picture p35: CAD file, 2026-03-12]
Schéma Proteus/Modèles 3D/TXS0108EPWR.step
6.40 x 1.20 x 6.50 mm

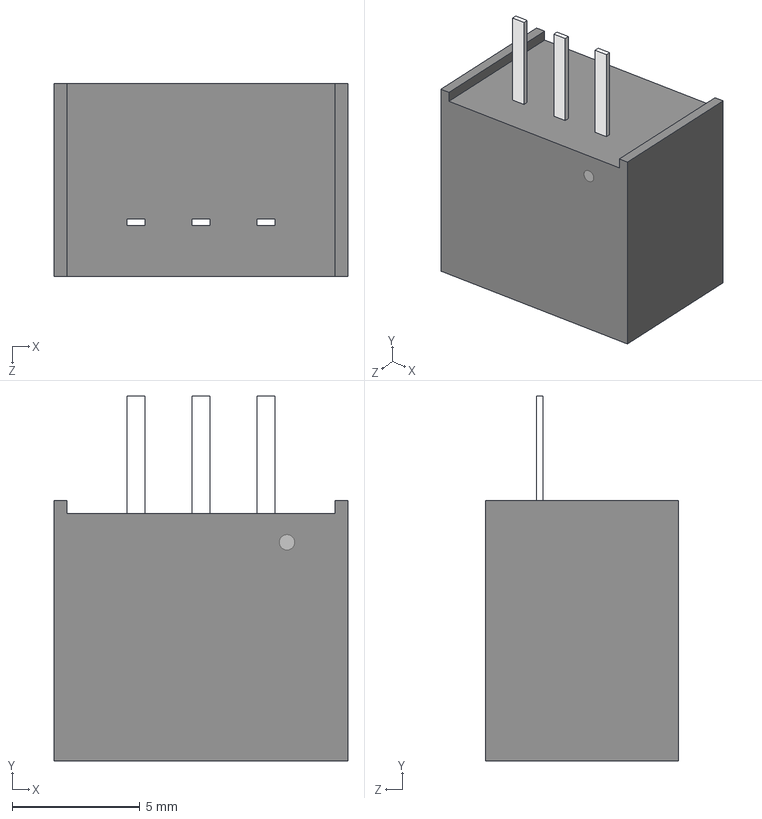
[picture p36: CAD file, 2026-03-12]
Schéma Proteus/Modèles 3D/TSR_0.5-2433.step
11.5 x 14.3 x 7.55 mm

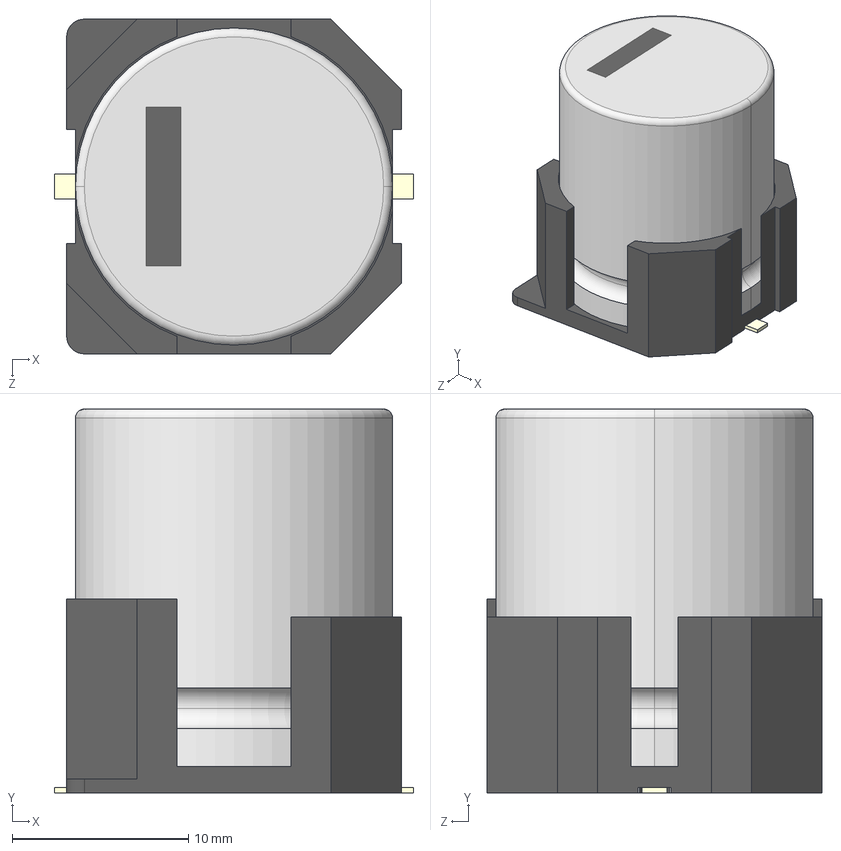
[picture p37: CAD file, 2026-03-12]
Schéma Proteus/Modèles 3D/EEEFK1C752SV.stp
20.4 x 21.8 x 19.0 mm
SIZE CODE K21-001
SIZE CODE K21-002
SIZE CODE K21-003 x 2
SIZE CODE K21-004 x 2

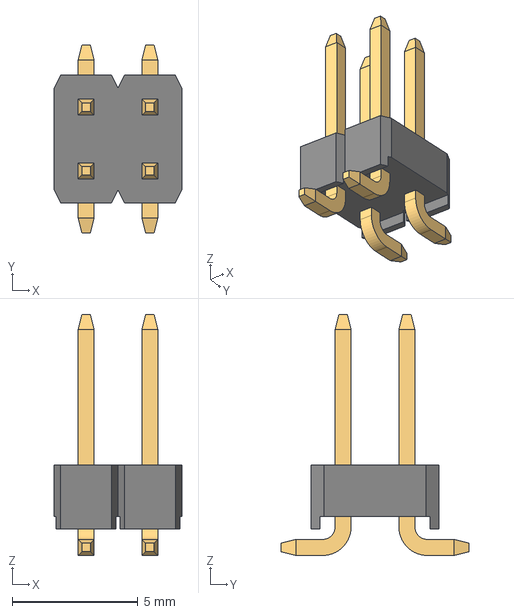
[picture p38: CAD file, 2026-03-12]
Schéma Proteus/Modèles 3D/6100XX21121_61000421121.step
5.08 x 7.50 x 9.60 mm
6100xx21121_PIN x 4

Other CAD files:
Schéma Proteus/Modèles 3D/Cap 0805.stp
Schéma Proteus/Modèles 3D/User Library-LEDSMD_0805_GREEN_H1P1(KP-2012VGC).step
Schéma Proteus/Modèles 3D/TB003-500-P02BE.step
Schéma Proteus/Modèles 3D/MCP3021.step
Schéma Proteus/Modèles 3D/691709710302.step
Schéma Proteus/Modèles 3D/RPM5.0-3.0.step

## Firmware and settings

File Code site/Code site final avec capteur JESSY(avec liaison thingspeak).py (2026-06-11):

import network
import socket
import urequests
import time
from machine import I2C, Pin, Timer

# ========= CONFIGURATION I2C (TFmini Plus) =========
i2c = I2C(0, sda=Pin(21), scl=Pin(22), freq=400000)

dist1, dist2, dist3, hauteur = 0, 0, 0, 0
error, count = 0, 0
max_error, max_marge = 2, 10
timer_period_ms, error_period_ms = 1000, 250
att_moy = 100
mesure_hauteur = 0
prep = 0
timer_sensor = None  # Sera initialisé plus bas

print("Recherche de capteurs I2C...")
devices = i2c.scan()
if devices:
    TFMINI_ADDR = devices[0]
    print("Capteur trouvé à l'adresse:", hex(TFMINI_ADDR))
else:
    print("Aucun capteur détecté. Adresse par défaut 0x10")
    TFMINI_ADDR = 0x10

# ========= THINGSPEAK =========
THINGSPEAK_WRITE_KEY = "Z5R36BOW4YA29JFK"
THINGSPEAK_URL       = "https://api.thingspeak.com/update"
last_upload = 0

# ========= WIFI (STABILISÉ) =========
print("Nettoyage des interfaces WiFi...")
try:
    # On récupère les instances
    sta_net = network.WLAN(network.STA_IF)
    ap_net = network.WLAN(network.AP_IF)
    
    # On ne les coupe que si elles sont déjà actives
    if sta_net.active(): sta_net.active(False)
    if ap_net.active(): ap_net.active(False)
    time.sleep_ms(300)
except Exception as e:
    print("Note: Pas de nettoyage nécessaire (", e, ")")

print("Démarrage WiFi AP (PROJET_PICO)...")
ap = network.WLAN(network.AP_IF)
ap.active(True)
ap.config(essid='PROJET_PICO', password='1234')
print("AP OK: PROJET_PICO / 192.168.4.1")

time.sleep_ms(500) 

print("Activation WiFi Station (Connexion BTS)...")
wlan = network.WLAN(network.STA_IF)
wlan.active(True)

time.sleep_ms(500) 

print("Tentative de connexion à la borne...")
wlan.connect('BTS_SN_IoT', 'BOU_BTS_SN')

# ========= FONCTIONS CAPTEUR =========
def get_distance():
    try:
        i2c.writeto(TFMINI_ADDR, b'\x5a\x05\x00\x01\x60')
        data = i2c.readfrom(TFMINI_ADDR, 9)
        if len(data) >= 9 and data[0] == 0x59 and data[1] == 0x59:
            distance = data[2] + (data[3] << 8)
            distance = round(distance * 1.05)
            return distance
    except:
        return None
    return None


def use_data():
    global dist1, dist2, dist3, hauteur, error, count, att_moy, prep, timer_sensor
    mesure = get_distance()

    if mesure is not None:
        if dist1 == 0:
            hauteur = mesure
            dist1 = mesure
            dist2 = mesure
            dist3 = mesure

        if 10 < mesure < 1200:
            if abs(mesure - hauteur) <= max_marge:
                dist3 = mesure

                time.sleep_ms(att_moy)
                mesure = get_distance()
                if mesure is None: mesure = dist3
                dist2 = mesure

                time.sleep_ms(att_moy)
                mesure = get_distance()
                if mesure is None: mesure = dist2
                dist1 = mesure

                hauteur = round((dist1 + dist2 + dist3) / 3)
                error = 0
                count += 1

                if count > prep:
                    print("Distance n°{}: {} cm".format(count, hauteur))

                if timer_sensor is not None:
                    timer_sensor.init(mode=Timer.PERIODIC, period=timer_period_ms, callback=interrupt_hauteur)

                return hauteur

            else:
                if timer_sensor is not None:
                    timer_sensor.init(mode=Timer.PERIODIC, period=error_period_ms, callback=interrupt_hauteur)
                error += 1
                if error > max_error:
                    error = 0
                    hauteur = mesure
                    dist1 = mesure
                    dist2 = mesure
                    dist3 = mesure
                    if timer_sensor is not None:
                        timer_sensor.init(mode=Timer.PERIODIC, period=timer_period_ms, callback=interrupt_hauteur)
                return hauteur
        else:
            print("Hors limite: {} cm".format(mesure))
            return hauteur
    return hauteur


def interrupt_hauteur(timer):
    global mesure_hauteur
    mesure_hauteur = 1


def read_all_values():
    return "----", hauteur, "----"


# ========= PAGE HTML =========
html_page = b'''<!DOCTYPE html>
<html lang="fr">
<head>
<meta charset="UTF-8">
<meta name="viewport" content="width=device-width,initial-scale=1">
<title>TFmini Plus | Station Riviere</title>
<style>
@import url('https://fonts.googleapis.com/css2?family=Orbitron:wght@400;700&family=Exo+2:wght@300;400;600&display=swap');
:root{
  --deep:#062a3a;--mid:#0a4a6b;--light:#1a7fa8;--accent:#00d4ff;
  --surface:rgba(10,74,107,0.45);--glass:rgba(255,255,255,0.07);
  --text:#d0f0ff;--muted:#7ab8d4;
}
*{margin:0;padding:0;box-sizing:border-box}
body{min-height:100vh;background:var(--deep);font-family:'Exo 2',sans-serif;color:var(--text);overflow-x:hidden;position:relative;}
.bg-waves{position:fixed;inset:0;z-index:0;overflow:hidden;pointer-events:none}
.wave{position:absolute;width:200%;height:200%;border-radius:40%;opacity:.08;animation:spin linear infinite}
.wave:nth-child(1){background:radial-gradient(ellipse,#00d4ff 0%,transparent 70%);top:-60%;left:-50%;animation-duration:18s}
.wave:nth-child(2){background:radial-gradient(ellipse,#0a9fd4 0%,transparent 70%);top:-40%;left:-30%;animation-duration:24s;animation-direction:reverse;opacity:.06}
.wave:nth-child(3){background:radial-gradient(ellipse,#062a3a 0%,#1a7fa8 60%,transparent 80%);top:20%;left:-60%;animation-duration:30s;opacity:.12}
@keyframes spin{to{transform:rotate(360deg)}}
.particles{position:fixed;inset:0;z-index:0;pointer-events:none}
.dot{position:absolute;border-radius:50%;background:var(--accent);animation:rise linear infinite;opacity:0}
@keyframes rise{0%{transform:translateY(0) scale(1);opacity:.6}100%{transform:translateY(-100vh) scale(0);opacity:0}}
.wrap{position:relative;z-index:1;max-width:480px;margin:0 auto;padding:24px 16px 40px}
header{text-align:center;margin-bottom:32px}
.logo-ring{width:72px;height:72px;border-radius:50%;border:2px solid var(--accent);display:flex;align-items:center;justify-content:center;margin:0 auto 14px;box-shadow:0 0 24px rgba(0,212,255,.35);animation:pulse 3s ease-in-out infinite;font-size:28px;}
@keyframes pulse{0%,100%{box-shadow:0 0 24px rgba(0,212,255,.35)}50%{box-shadow:0 0 42px rgba(0,212,255,.65)}}
h1{font-family:'Orbitron',sans-serif;font-size:1.35rem;letter-spacing:3px;color:var(--accent);text-shadow:0 0 18px rgba(0,212,255,.5)}
.subtitle{font-size:.78rem;color:var(--muted);letter-spacing:2px;margin-top:4px;text-transform:uppercase}
.status-bar{display:flex;align-items:center;gap:8px;background:var(--glass);border:1px solid rgba(0,212,255,.15);border-radius:30px;padding:7px 16px;margin-bottom:24px;font-size:.75rem;color:var(--muted);letter-spacing:1px;}
.dot-live{width:77px;height:7px;border-radius:50%;background:#00ff88;box-shadow:0 0 8px #00ff88;animation:blink 1.4s ease-in-out infinite}
@keyframes blink{0%,100%{opacity:1}50%{opacity:.3}}
.hero-card{background:linear-gradient(135deg,rgba(0,212,255,.12),rgba(10,74,107,.6));border:1px solid rgba(0,212,255,.3);border-radius:20px;padding:28px 24px;margin-bottom:16px;text-align:center;position:relative;overflow:hidden;box-shadow:0 8px 32px rgba(0,0,0,.4),inset 0 1px 0 rgba(255,255,255,.08);}
.hero-card::before{content:'';position:absolute;inset:0;background:repeating-linear-gradient(90deg,transparent,transparent 19px,rgba(0,212,255,.04) 20px),repeating-linear-gradient(0deg,transparent,transparent 19px,rgba(0,212,255,.04) 20px);}
.hero-label{font-size:.7rem;letter-spacing:3px;text-transform:uppercase;color:var(--muted);margin-bottom:8px}
.hero-value{font-family:'Orbitron',sans-serif;font-size:4rem;font-weight:700;color:#fff;line-height:1;text-shadow:0 0 30px rgba(0,212,255,.7);}
.hero-unit{font-size:.95rem;color:var(--accent);letter-spacing:2px;margin-top:6px}
.water-bar-wrap{margin-top:18px;background:rgba(0,0,0,.3);border-radius:30px;height:10px;overflow:hidden}
.water-bar{height:100%;border-radius:30px;background:linear-gradient(90deg,#0a9fd4,#00d4ff);transition:width 1s ease;box-shadow:0 0 12px rgba(0,212,255,.6)}
.cards-grid{display:grid;grid-template-columns:1fr 1fr;gap:12px;margin-bottom:12px}
.card{background:var(--surface);border:1px solid rgba(255,255,255,.08);border-radius:16px;padding:18px 14px;position:relative;overflow:hidden;transition:transform .2s;box-shadow:0 4px 20px rgba(0,0,0,.3);}
.card:active{transform:scale(.97)}
.card::after{content:'';position:absolute;top:-30px;right:-30px;width:80px;height:80px;border-radius:50%;background:radial-gradient(circle,rgba(0,212,255,.1),transparent);}
.card-icon{font-size:1.5rem;margin-bottom:8px}
.card-label{font-size:.65rem;text-transform:uppercase;letter-spacing:2px;color:var(--muted);margin-bottom:6px}
.card-val{font-family:'Orbitron',sans-serif;font-size:1.6rem;font-weight:700;color:#fff}
.card-unit{font-size:.65rem;color:var(--accent);letter-spacing:1px;margin-top:2px}
footer{text-align:center;margin-top:28px;font-size:.65rem;color:rgba(122,184,212,.4);letter-spacing:2px}
</style>
</head>
<body>
<div class="bg-waves"><div class="wave"></div><div class="wave"></div><div class="wave"></div></div>
<div class="particles" id="pts"></div>
<div class="wrap">
  <header>
    <div class="logo-ring">&#x1F30A;</div>
    <h1>STATION RIVIERE</h1>
    <div class="subtitle">TFmini Plus LiDAR &mdash; Surveillance Hydrologique</div>
  </header>
  <div class="status-bar"><span class="dot-live"></span><span>LIVE &mdash; Mise &agrave; jour toutes les 500ms</span></div>
  <div class="hero-card">
    <div class="hero-label">&#x1F4CF; Distance mesur&eacute;e</div>
    <div class="hero-value" id="eau">---</div>
    <div class="hero-unit">CENTIMETRES</div>
    <div class="water-bar-wrap"><div class="water-bar" id="bar" style="width:0%"></div></div>
  </div>
  <div class="cards-grid">
    <div class="card">
      <div class="card-icon">&#x1F50B;</div>
      <div class="card-label">Batterie</div>
      <div class="card-val" id="bat">---</div>
      <div class="card-unit">VOLTS</div>
    </div>
    <div class="card">
      <div class="card-icon">&#x2600;&#xFE0F;</div>
      <div class="card-label">Panneau solaire</div>
      <div class="card-val" id="panneau">---</div>
      <div class="card-unit">AMPERES</div>
    </div>
  </div>
  <footer>PROJET PICO &mdash; ESP32 &mdash; TFmini Plus I2C &mdash; 2026</footer>
</div>
<script>
(function(){
  var c=document.getElementById('pts');
  for(var i=0;i<18;i++){
    var d=document.createElement('div');d.className='dot';
    var s=Math.random()*4+2;
    d.style.cssText='width:'+s+'px;height:'+s+'px;left:'+Math.random()*100+'%;bottom:'+Math.random()*20+'%;animation-duration:'+(Math.random()*12+8)+'s;animation-delay:'+(Math.random()*10)+'s;opacity:0';
    c.appendChild(d);
  }
})();
var MAX_H=1200;
function upd(){
  fetch('/data').then(function(r){return r.text();}).then(function(d){
    var v=d.split(',');
    var bat=v[0]||'---',eau=parseInt(v[1])||0,pan=v[2]||'---';
    document.getElementById('bat').textContent=bat;
    document.getElementById('panneau').textContent=pan;
    document.getElementById('eau').textContent=isNaN(eau)?'---':eau;
    document.getElementById('bar').style.width=Math.min(100,Math.round(eau/MAX_H*100))+'%';
  }).catch(function(){});
}
upd();setInterval(upd,500);
</script>
</body>
</html>'''

# ========= INITIALISATION TIMER =========
print("Démarrage timer capteur...")
timer_sensor = Timer(0)
timer_sensor.init(mode=Timer.PERIODIC, period=timer_period_ms, callback=interrupt_hauteur)

# ========= SERVEUR WEB =========
print("Démarrage serveur web...")
s = socket.socket(socket.AF_INET, socket.SOCK_STREAM)
s.setsockopt(socket.SOL_SOCKET, socket.SO_REUSEADDR, 1)
s.bind(('', 80))
s.listen(5)
s.setblocking(False)

print("Système prêt.")

# ========= BOUCLE PRINCIPALE =========
while True:

    if mesure_hauteur == 1:
        hauteur = use_data()
        mesure_hauteur = 0

    # Envoi ThingSpeak uniquement si la Station est bien connectée au réseau
    if wlan.isconnected() and (time.time() - last_upload > 15):
        try:
            url = "{}?api_key={}&field1={}".format(THINGSPEAK_URL, THINGSPEAK_WRITE_KEY, hauteur)
            r = urequests.get(url)
            r.close()
            last_upload = time.time()
            print("ThingSpeak OK: {}cm".format(hauteur))
        except Exception as e:
            print("Erreur d'envoi ThingSpeak:", e)

    try:
        conn, addr = s.accept()
        conn.setblocking(True)
        request = conn.recv(1024)
        req = str(request)

        if '/data' in req:
            bat, eau, panneau = read_all_values()
            response = "{},{},{}".format(bat, eau, panneau)
            conn.send(b'HTTP/1.1 200 OK\r\nContent-Type: text/plain\r\n\r\n' + response.encode())
        else:
            conn.send(b'HTTP/1.1 200 OK\r\nContent-Type: text/html\r\n\r\n' + html_page)

        conn.close()
    except OSError:
        pass
    except Exception as e:
        print("Erreur serveur web:", e)

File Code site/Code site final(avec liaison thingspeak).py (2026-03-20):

import network
import socket
import urequests
import time
from machine import ADC, Pin

# ========= CAPTEURS (réels, debug seulement) =========
# On déclare les entrées ADC pour les 4 capteurs (même si seulement 2 sont utilisés)
adc_bat = ADC(Pin(34))      # Batterie
adc_conso = ADC(Pin(32))    # Hauteur eau (valeur brute)
adc_courant = ADC(Pin(33))  # Hauteur vanne (valeur brute)
adc_panneau = ADC(Pin(35))  # Panneau solaire

# ========= THINGSPEAK =========
# Clé d'écriture de ton canal ThingSpeak
THINGSPEAK_WRITE_KEY = "Z5R36BOW4YA29JFK"
# URL de l'API ThingSpeak pour mettre à jour un canal
THINGSPEAK_URL = "https://api.thingspeak.com/update"
last_upload = 0             # Dernier instant où une donnée a été envoyée

# ========= SIMULATION RÉALISTE =========
# Valeurs de simulation pour remplacer les capteurs réels
eau_val = 175          # Hauteur eau départ (cm)
eau_dir = -1           # Direction : -1 = descend, +1 = monte
vanne_offset = 30      # Vanne toujours 30 cm sous l'eau

# ========= DOUBLE WIFI =========
# Création du point d'accès (hotspot) projet
ap = network.WLAN(network.AP_IF)      # Hotspot PROJET_PICO
ap.active(True)                       # On active le mode AP
ap.config(essid='PROJET_PICO', password='1234')   # Nom + mot de passe

# Création de la connexion STA (client WiFi)
wlan = network.WLAN(network.STA_IF)   # Mode station (se connecter au réseau BTS)
wlan.active(True)                     # On active le mode STA
wlan.connect('BTS_SN_IoT', 'BOU_BTS_SN')  # On se connecte au réseau
print("Connexion BTS...")
while not wlan.isconnected():
    time.sleep(1)
ip_bts = wlan.ifconfig()[0]           # On récupère l'IP obtenue
print("BTS IP:", ip_bts)
print("Hotspot: 192.168.4.1")

def update_fake_values():
    """Simulation RÉALISTE : eau 150↔200cm, vanne=eau-30cm"""
    global eau_val, eau_dir

    # On fait varier la hauteur eau lentement (+/-1cm)
    eau_val += eau_dir
    if eau_val >= 200:
        eau_val = 200
        eau_dir = -1
    elif eau_val <= 150:
        eau_val = 150
        eau_dir = 1

    # Vanne TOUJOURS 30 cm sous l'eau (physique respectée)
    vanne_val = eau_val - vanne_offset
    print(f"SIMUL: Eau={eau_val}cm | Vanne={vanne_val}cm")
    return eau_val, vanne_val   # <-- on retourne les deux valeurs calculées

def read_local_sensors():
    """UNE SEULE fonction : debug ADC + simulation réaliste"""
    # Lecture brute des capteurs (pour le debug dans la console)
    bat_raw = adc_bat.read_u16()
    eau_raw = adc_conso.read_u16()
    vanne_raw = adc_courant.read_u16()
    panneau_raw = adc_panneau.read_u16()
    print("RAW: B=", bat_raw, "E=", eau_raw, "V=", vanne_raw, "P=", panneau_raw)

    # Pour l'instant, batterie et panneau ne sont pas gérés = "----"
    bat = "----"
    panneau = "----"

    # On utilise la simulation réaliste pour eau et vanne
    eau, vanne = update_fake_values()   # <- récupération des valeurs simulées

    return bat, eau, vanne, panneau

def send_thingspeak(eau, vanne):
    """Envoi FORCÉ vers ThingSpeak (même simulation)"""
    global last_upload
    try:
        # Construction de l'URL ThingSpeak avec la clé et les champs
        url = (
            THINGSPEAK_URL +
            "?api_key=" + THINGSPEAK_WRITE_KEY +
            "&field1=" + str(eau) +        # Hauteur eau
            "&field2=" + str(vanne)         # Hauteur vanne
        )
        r = urequests.get(url)
        print("ThingSpeak OK:", r.text)  # "123" = numéro de l'entrée créée
        r.close()
        last_upload = time.time()
    except Exception as e:
        print("ThingSpeak ERREUR:", str(e)[:30])

def json_data():
    """Données pour page web : "----,175,145,----" """
    bat, eau, vanne, panneau = read_local_sensors()
    # On renvoie une chaîne CSV simple : bat,eau,vanne,panneau
    return f"{bat},{eau},{vanne},{panneau}"

# ========= PAGE WEB =========
# Page HTML affichée sur le hotspot (192.168.4.1)
# ========= PAGE WEB (nouveau design) =========
html_page = '''<html>
<head>
    <meta name="viewport" content="width=device-width, initial-scale=1.0">
    <title>PROJET PICO</title>
    <style>
        body {
            background: #f4f6f9;
            color: #2c3e50;
            font-family: 'Segoe UI', Tahoma, Geneva, Verdana, sans-serif;
            margin: 0;
            padding: 20px;
        }
        h1 {
            text-align: center;
            margin: 20px 0;
            color: #2c3e50;
            font-weight: 600;
        }
        .card {
            background: white;
            border-radius: 12px;
            box-shadow: 0 4px 12px rgba(0,0,0,0.08);
            padding: 15px 20px;
            margin: 10px 0;
            display: flex;
            align-items: center;
            justify-content: space-between;
            transition: transform 0.1s ease, box-shadow 0.1s ease;
        }
        .card:hover {
            transform: translateY(-2px);
            box-shadow: 0 6px 16px rgba(0,0,0,0.12);
        }
        .card-title {
            font-size: 16px;
            font-weight: 500;
            color: #7f8c8d;
            margin: 0 0 5px 0;
        }
        .card-value {
            font-size: 36px;
            margin: 0;
            font-weight: 700;
            color: #2c3e50;
        }
        .unit {
            font-size: 14px;
            color: #7f8c8d;
            margin-left: 6px;
        }
        .no-sensor {
            color: #e74c3c !important;
        }
        .ok {
            color: #27ae60 !important;
        }
    </style>
    <script>
        function updateValues(){
            fetch("/data")
            .then(r => r.text())
            .then(d => {
                const v = d.split(",");
                document.getElementById("bat").innerHTML = v[0];
                document.getElementById("conso").innerHTML = v[1];
                document.getElementById("courant").innerHTML = v[2];
                document.getElementById("panneau").innerHTML = v[3];

                colorStatus("bat", v[0]);
                colorStatus("conso", v[1]);
                colorStatus("courant", v[2]);
                colorStatus("panneau", v[3]);
            });
        }

        function colorStatus(id, val){
            const el = document.getElementById(id);
            el.className = (val == "----") ? "card-value no-sensor" : "card-value ok";
        }

        setInterval(updateValues, 2000);
        updateValues();
    </script>
</head>
<body>
    <h1>PROJET PICO</h1>

    <div class="card">
        <div>
            <div class="card-title">Batterie</div>
            <div class="card-value no-sensor" id="bat">----</div>
        </div>
        <div class="unit">V</div>
    </div>

    <div class="card">
        <div>
            <div class="card-title">Hauteur eau</div>
            <div class="card-value no-sensor" id="conso">----</div>
        </div>
        <div class="unit">cm</div>
    </div>
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

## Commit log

2026-01-08 Implement LoRaE32 class for data transmission
    This code implements a LoRaE32 class for sending and receiving data using LoRa technology. It includes methods for configuring the device, sending data, and receiving incoming packets.
2026-01-08 Add LoRaE32 class for LoRa communication
    Implement LoRaE32 class for UART communication and data transmission.
2026-02-20 Datasheet
    Datasheet de tout les composants
2026-02-20 Proteus
    Schéma Proteus Partie Alimentation
    [MCP3021.step, RPM5.0-3.0.step]
2026-02-20 Rapport
    Début de Rapport de Projet
2026-02-20 Tableur
    Classements des composants et de leurs consommation + Courbe Torque(couple) du moteur
    [Tableur conso composants.xlsx]
2026-02-20 Proteus
    Schéma pour les montages
